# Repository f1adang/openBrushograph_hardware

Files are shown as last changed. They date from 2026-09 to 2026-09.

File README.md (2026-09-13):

# openBrushograph
openBrushograph
A simple, open source and DIY x-y gantry and z-mechanism for making a brush painting robot. Formerly know as Brušograf...

## Quick links
- `X-Y_freeCAD/`: Parametric FreeCAD gantry models and STLs
- `Z-mechanism_openSCAD/`: Parametric OpenSCAD brush lift models and STLs
- LICENSES/: CERN-OHL-S/W/P and CC BY-SA texts

## Overview
openBrushograph is a small CNC-style plotter for brushes and pens. The X–Y gantry is modeled in FreeCAD and the Z mechanism in OpenSCAD.

Full background, tutorials and history live on the SGMK wiki:
https://wiki.sgmk-ssam.ch/wiki/Brushograph

openBrushograph

## Downloads (FreeCAD & Pre-exported STLs)

If you just want to get printing immediately, you can grab the FreeCAD source file or the pre-exported STL folders below:
- **FreeCAD Source File:** [brushograf_V6.FCStd](X-Y_freeCAD/brushograf_V6.FCStd)

### Standard Version
- **Mini Variant (M3=2.7mm):** [STLs/brushograf_V6_Mini_M3_2.7mm_STLs](X-Y_freeCAD/STLs/brushograf_V6_Mini_M3_2.7mm_STLs/)
- **Z-Mechanism STLs:** [Z-mechanism_V4_STL](Z-mechanism_openSCAD/Z-mechanism_V4_STL/)

### Special Designs
- **Micro Variant (M3=2.7mm):** [STLs/brushograf_V6_Micro_M3_2.7mm_STLs](X-Y_freeCAD/STLs/brushograf_V6_Micro_M3_2.7mm_STLs/)

*Note: Endless custom versions can be generated using the FreeCAD parameters! For example, you can easily adjust the hole sizes to perfectly fit heated metal threaded inserts, or completely change the general dimensions of the gantry to suit your specific needs (see the **Parametric FreeCAD Design** section below).*

## Parametric FreeCAD Design
The X-Y gantry is designed in FreeCAD as a fully parametric model. 

### Adjusting Parameters
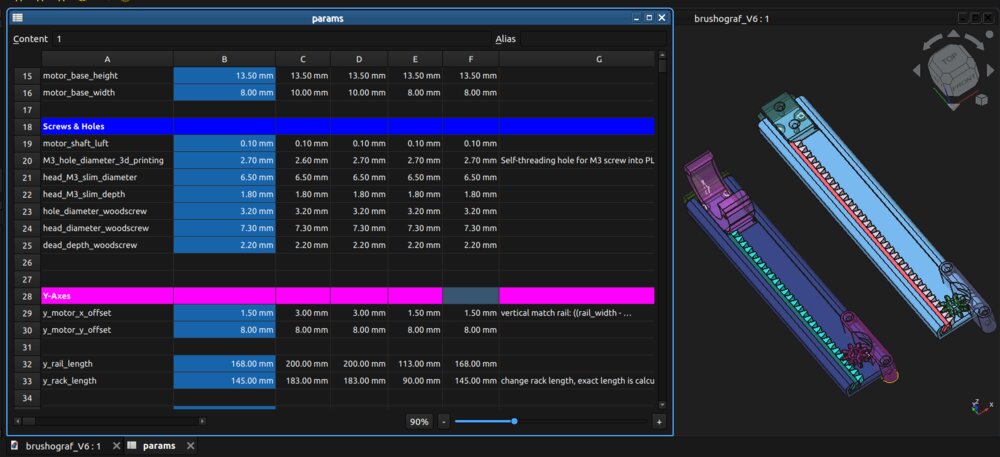
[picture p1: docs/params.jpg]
Spreadsheet Parameters


Inside the FreeCAD file (`X-Y_freeCAD/brushograf_V6.FCStd`), you will find a dedicated Spreadsheet object called `params`. This spreadsheet drives the entire 3D geometry!
- You can easily customize the design by modifying values in the parameter rows (e.g., changing the `M3_hole_diameter_3d_printing`).
- The design supports multiple **variants** (e.g., Mini, Micro, Baby). The variant names are defined as column headers in the first row of the spreadsheet (starting from column C).
- By changing the master Switcher value (cell `B1`) to the corresponding column index (1 for C, 2 for D, etc.), FreeCAD will instantly recompute the entire model for that specific variant!

### Automated STL Export Script
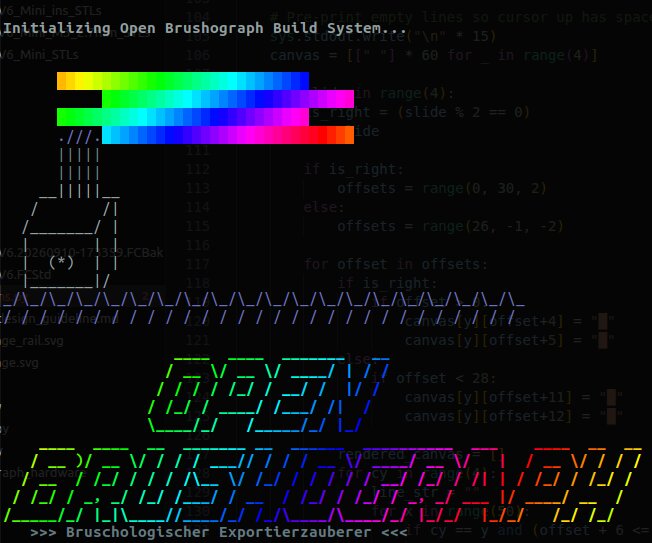
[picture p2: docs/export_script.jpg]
Terminal Export Wizard


To streamline the export process, we include a python build script (`build_versions.py`). 
Running this script via FreeCAD's command line will:
1. Dynamically read your custom variant names from the spreadsheet.
2. Provide an interactive terminal wizard to select which variants you want to build (or build all of them!).
3. Allow you to override specific parameters on the fly (like the M3 hole diameter).
4. Automatically toggle the spreadsheet switcher, force a deep geometry recompute, and export clean STL folders ready for 3D printing directly into the `X-Y_freeCAD/STLs/` directory.

**How to run the script:**
Open a terminal inside the `X-Y_freeCAD` directory and run:
```bash
FreeCADCmd build_versions.py brushograf_V6.FCStd
```
*(Note: Depending on your OS and installation, the FreeCAD command line tool may be named `freecadcmd`, `FreeCADCmd`, or accessed via flatpak: `flatpak run --command=FreeCADCmd org.freecad.FreeCAD`)*

## Parametric OpenSCAD Z-Mechanism
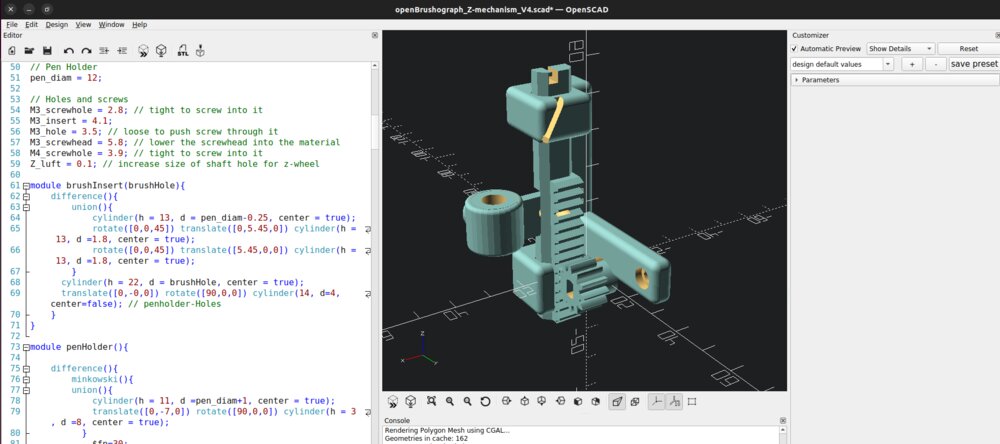
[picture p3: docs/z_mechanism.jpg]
OpenSCAD Z-Mechanism


In addition to the FreeCAD X-Y gantry, the Z-mechanism for the brush lift is also fully parametric, designed natively in OpenSCAD!
- You can find the source file and pre-compiled STLs in the `Z-mechanism_openSCAD/` directory.
- Simply open the `.scad` file in OpenSCAD and you can easily tweak variables like mounting hole sizes, brush holder dimensions, and motor fittings before generating your custom STL.

### Extra OpenSCAD Accessories
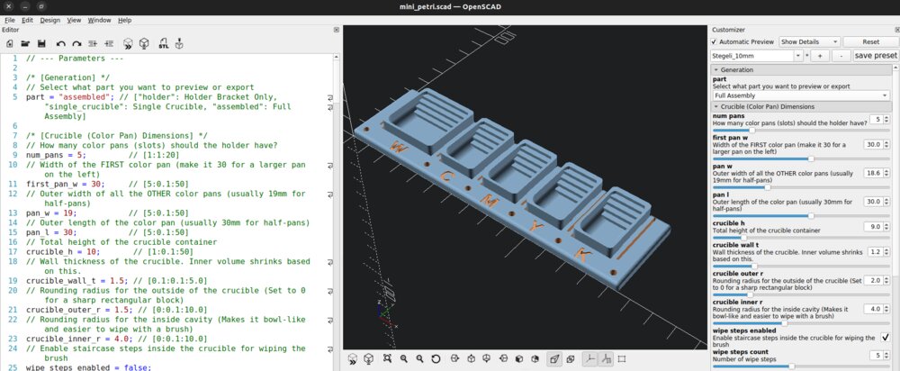
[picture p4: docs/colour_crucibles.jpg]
OpenSCAD Accessories


The OpenSCAD directory also includes parametric models for various extra parts! You can easily generate custom colour holders, petri dishes, and other useful accessories to complete your robotic painting setup.

## Setup options (controllers/firmware)
- FluidNC (ESP32 with WebUI): https://installer.fluidnc.com/
  - About FluidNC: http://wiki.fluidnc.com/en/home
- Arduino (GRBL): https://github.com/gnea/grbl
  - GRBL fork for 28BYJ-48 unipolar steppers: https://github.com/TGit-Tech/GRBL-28byj-48
- Universal Gcode Sender (UGS): https://winder.github.io/ugs_website/

See details and tips on the wiki: https://wiki.sgmk-ssam.ch/wiki/Brushograph#How_to_set_it_up

## Printing and Assembly
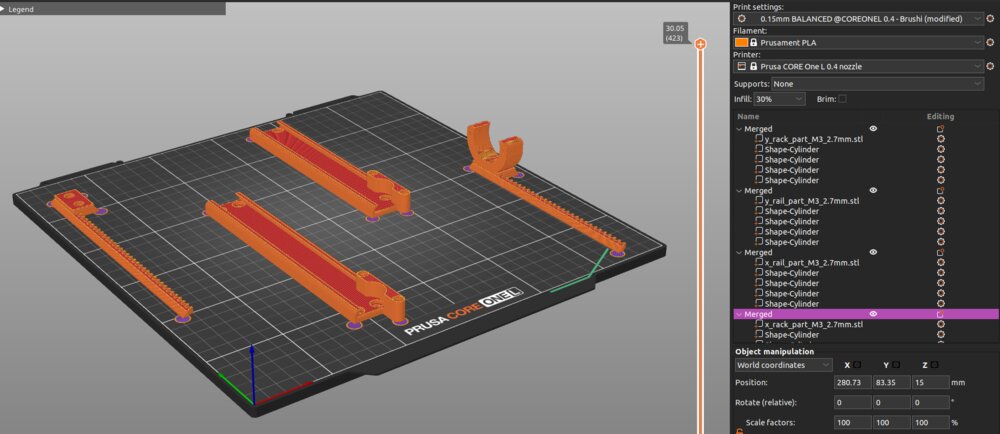
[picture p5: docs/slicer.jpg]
Prusa Slicer Preview


### Recommended Materials
For mechanical rigidity and durability, **PLA+** or better **High Temperature PLA+**, other materials such as **PETG** is highly recommended. Standard PLA is also acceptable but may be brittle under high stress or will bend easily in warm environments or in direct sunshine.

The pinions were also printed in other advanced filaments, such as PA612-CF15 for even better mechanical and thermal properties.

### Slicer Settings
For structural parts (like the gantry mounts and Z-mechanism):
- **Perimeters/Walls:** 3 to 4 walls for maximum structural strength.
- **Infill:** 20% to 30% Gyroid.
- **Layer Height:** 0.2mm is an excellent balance between speed and tolerance. For aesthetic reason smaller layer heights can be used.
- **Mouse-ears** are more usefull than larger brims if you have adhesion issues.

### Orientation and Supports
- The pre-exported STLs are generally oriented in their optimal printing position. 
- All parts are designed to print completely **support-free**.

### Hardware and Assembly
- **Threaded Inserts:** Hols can designed specifically for heated metal threaded inserts (e.g. M3). Use a soldering iron to press them in carefully.
- If you find the default hole sizes are too tight or loose for your specific inserts, remember you can always tweak the `M3_hole_diameter_3d_printing` parameter in the FreeCAD spreadsheet and re-export the STLs using the build script!

More context, detailed assembly instructions and legacy designs: https://wiki.sgmk-ssam.ch/wiki/Brushograph#Printing_and_assembling_the_Brushograph

## Bill of Materials (BOM) (in progress...)
A quick overview of the required printed parts and hardware is below:

### X-Y Assembly
| Assembly | Part | Qty | Notes |
|---|---|-----|---|
| X | `openBrushograph_x_rail_part.stl` | 1 | Print |
| X | `openBrushograph_x_rack_part.stl` | 1 | Print; higher infill recommended |
| X | `openBrushograph_x_pinion_part.stl` | 1 | Print (its same as y_pinion) |
| X | `openBrushograph_x_endstop_part.stl` | 1 | Print |
| Y | `openBrushograph_y_rail_part.stl` | 1 | Print |
| Y | `openBrushograph_y_rack_part.stl` | 1 | Print; higher infill recommended |
| Y | `openBrushograph_y_pinion_part.stl` | 1 | Print (its same as x_pinion) |

### Z Assembly
| Assembly | Part | Qty | Notes |
|---|---|-----|---|
| Z | `openBrushograph_rail_Z-mechanism.stl` | 1 | Print |
| Z | `openBrushograph_rack_Z-mechanism.stl` | 1 | Print |
| Z | `openBrushograph_handWheel.stl` | 1 | Print |
| Z | `openBrushograph_penHolder_Insert_6.5.stl` | 1 | Variants available for different brushes |

### Screws & Hardware
| Type | Image | Part | Qty | Notes |
|---|---|---|-----|---|
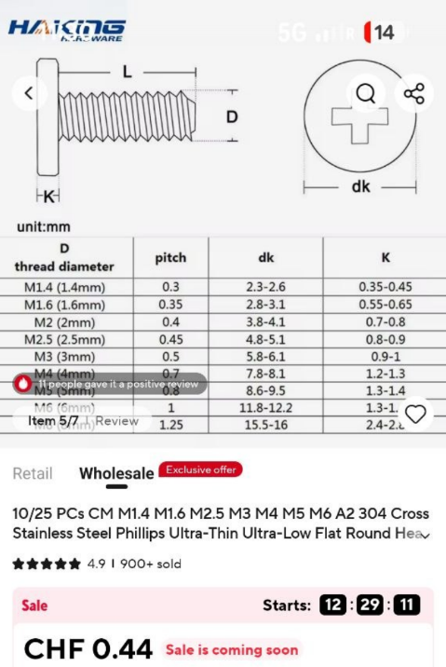
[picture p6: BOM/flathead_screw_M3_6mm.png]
| flat-head Screw | [](BOM/flathead_screw_M3_6mm.png) | M3x6 | 4 | to fit below the rack into the rails. [Shop Link](https://www.aliexpress.com/item/1005003126053325.html) |
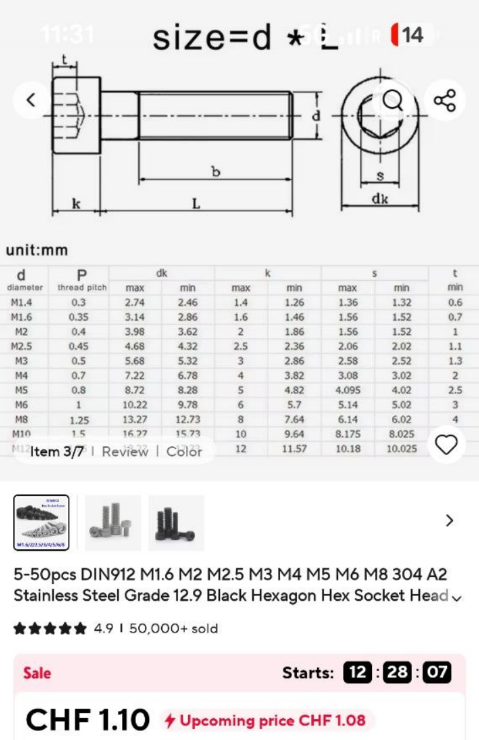
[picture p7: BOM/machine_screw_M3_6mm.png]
| machine Screw | [](BOM/machine_screw_M3_6mm.png) | M3x6 | 6 | to mount the motors. mbe use longer ones on the z-axes. [Shop Link](https://www.aliexpress.com/item/32810872544.html) |
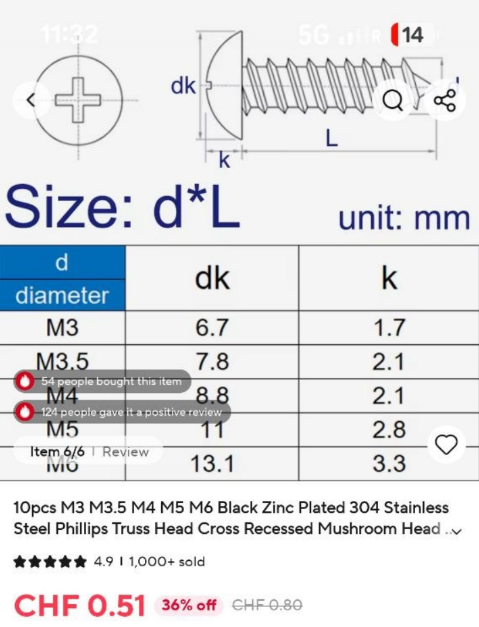
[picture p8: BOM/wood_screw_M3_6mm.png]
| Wood-Screw | [](BOM/wood_screw_M3_6mm.png) | M3x6 | 4 | Longer screws if you have a thick wooden base board. [Shop Link](https://www.aliexpress.com/item/1005009268426636.html) |
| Screw | | M4x16 | 1 | for handWheel |

### Optional: Threaded Inserts
| Type | Part | Qty | Notes |
|---|---|-----|---|
| Threaded Insert | M3 | 10 | For a stronger assembly. |

*Note: If you are using threaded inserts, a different model variant with wider holes has to be printed, or the standard holes can simply be drilled out with a 4mm drill bit to make them wider.*

### Electronics / PCB
The BOM and design files for the custom printed circuit board (PCB) are documented in a dedicated repository:
[Brushograph_PCB](https://github.com/openBrushograph/Brushograph_PCB)

Brushograph PCB

## Related links and credits
### Credits
General openBrushograph concept and artistic director, Dominik Mahnic: https://app.assembla.com/spaces/dominik-mahnic/wiki
X–Y: FreeCAD version designed by Stahl: https://github.com/stahlnow
Z: OpenSCAD version designed by dusjagr: https://github.com/dusjagr

### Where the inspirations came from
- Z-mechanism inspiration (Thingiverse): https://www.thingiverse.com/thing:7050508
- Earlier mini plotter references:
  - https://www.thingiverse.com/thing:4579436
  - https://www.thingiverse.com/thing:4607077
  - https://www.thingiverse.com/thing:4796222
  - https://www.thingiverse.com/thing:5719788
 
## License
- Hardware: CERN-OHL-S-2.0 (see LICENSE and LICENSES/)
- Documentation: CC BY-SA 4.0

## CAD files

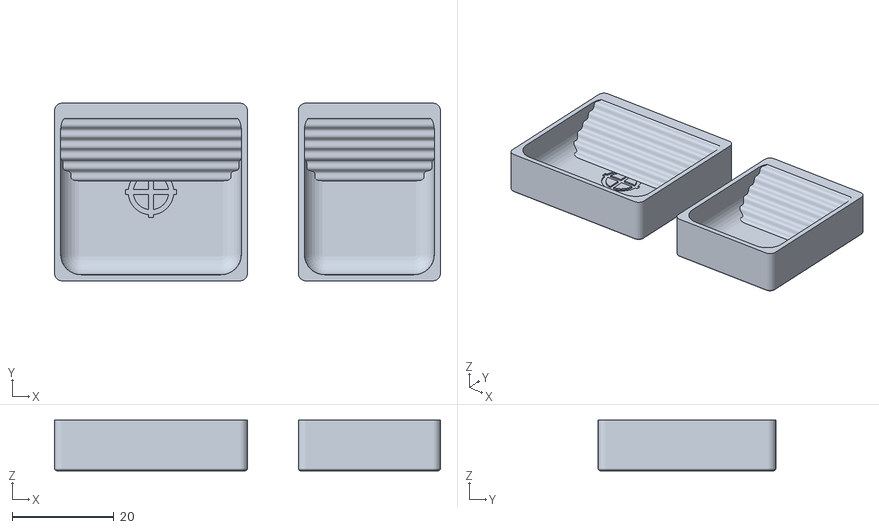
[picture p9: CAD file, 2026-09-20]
Extras/CMYK_ColourContainers/CMYK_standard_containers_steps.stl
76.0 x 35.0 x 10.0

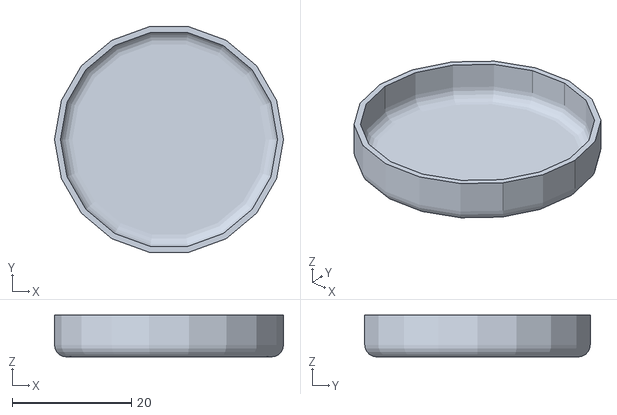
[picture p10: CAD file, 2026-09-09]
Extras/petri_ColourContainers/Petri39mm.obj
38.4 x 37.8 x 7.00

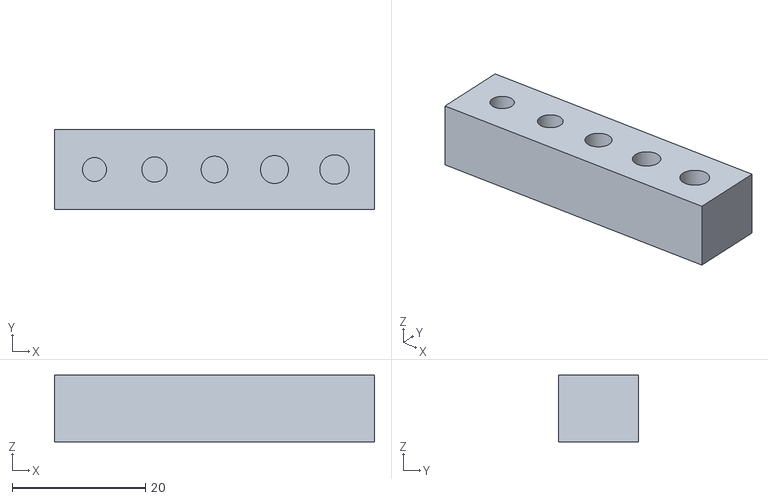
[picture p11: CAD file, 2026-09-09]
Extras/tests/insert_test.stl
48.0 x 12.0 x 10.0

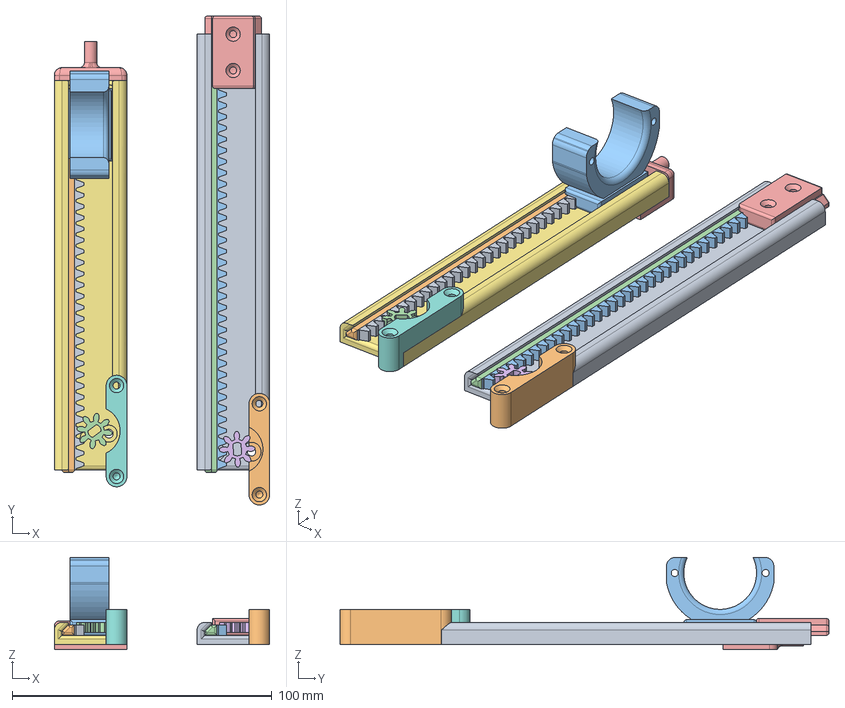
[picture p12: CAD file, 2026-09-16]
X-Y_freeCAD/brushograf_V6.FCStd
83.0 x 188.4 x 35.5 mm
y_rail
y_motor_base
y_rack
y_rack_fit
y_carriage
y_pinion
x_rail
x_motor_base
x_rack
x_rack_fit
x_carriage
x_pinion
x_endstop

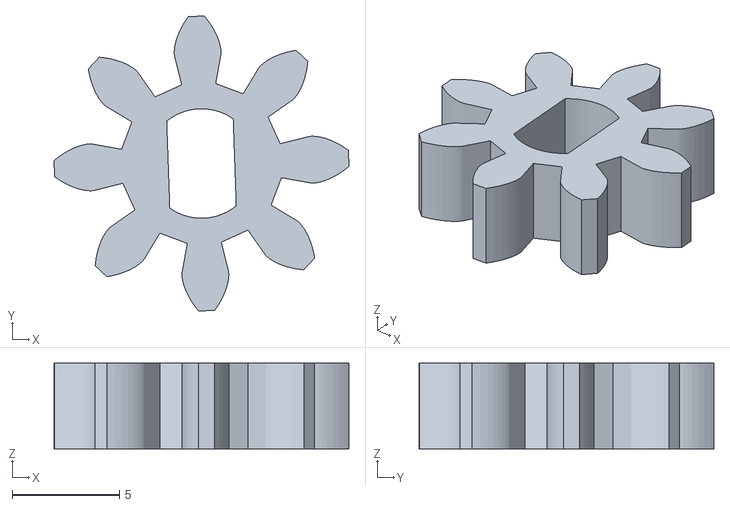
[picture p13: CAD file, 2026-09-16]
X-Y_freeCAD/STLs/brushograf_V6_Mikro_M3_2.7mm/y_pinion_Mikro_M3_2.7mm.stl
13.7 x 13.7 x 4.00

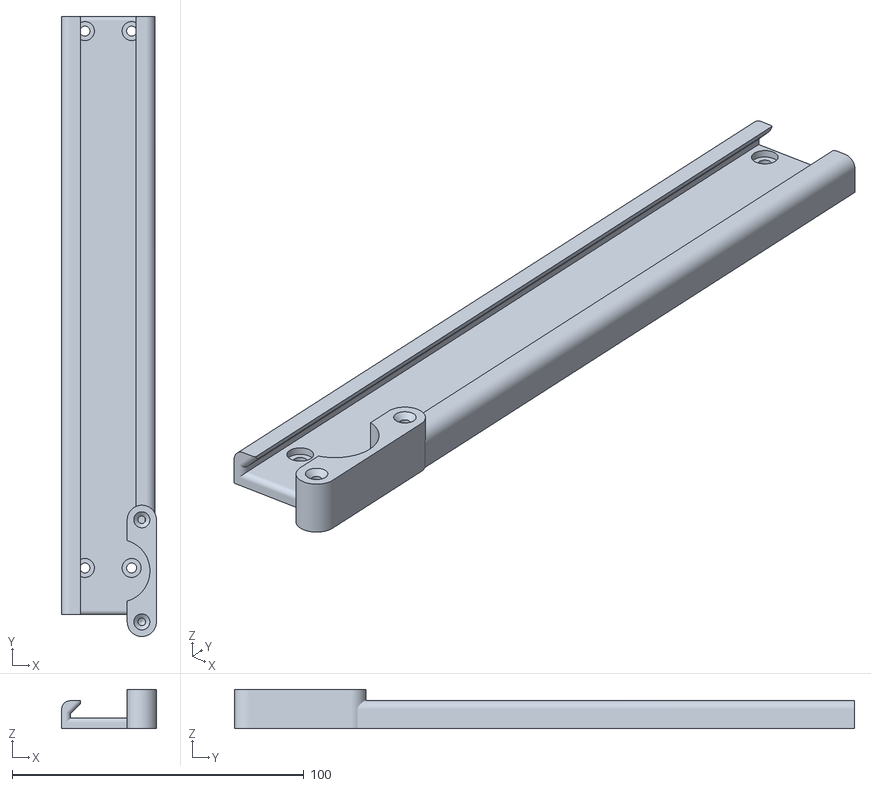
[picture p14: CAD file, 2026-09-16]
X-Y_freeCAD/STLs/brushograf_V6_Mini_M3_2.7mm/x_rail_Mini_M3_2.7mm.stl
32.5 x 212.5 x 13.5

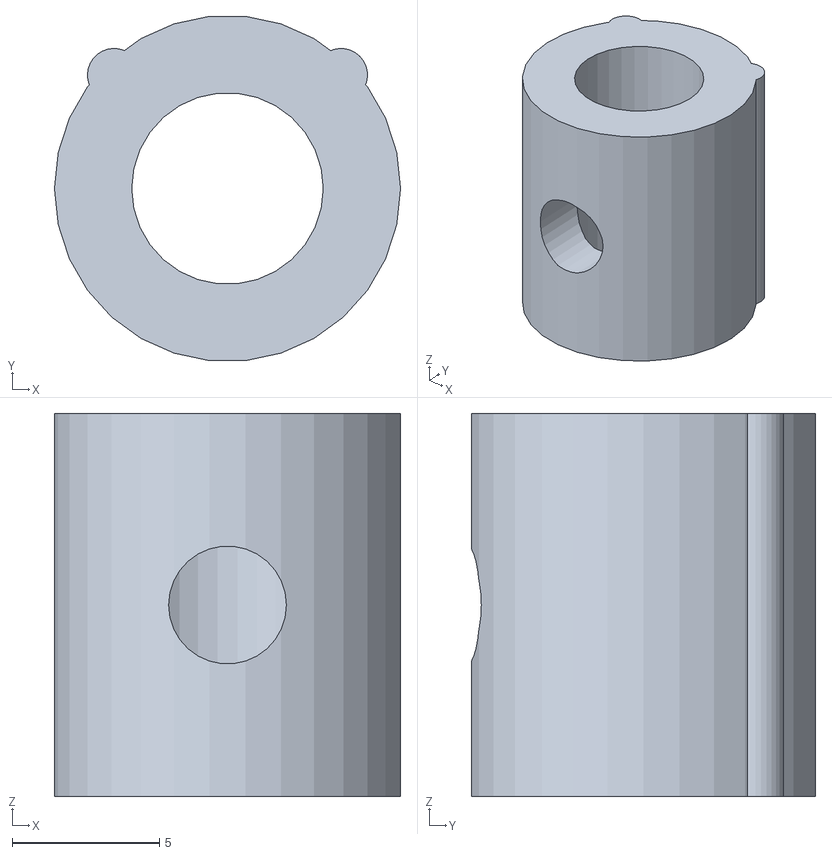
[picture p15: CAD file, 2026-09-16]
Z-mechanism_openSCAD/brushHolder/standard_brush_insert_6.5mm_Z-mechanism.stl
11.8 x 11.7 x 13.0

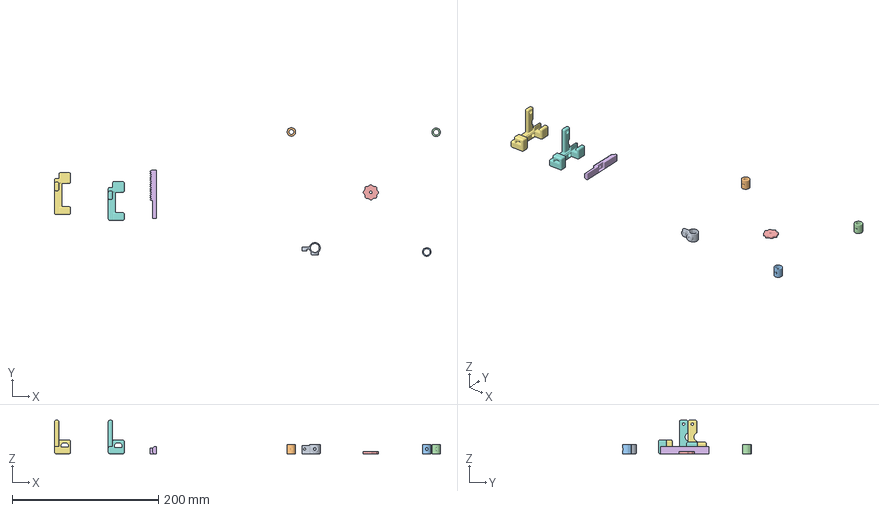
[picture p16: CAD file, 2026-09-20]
Z-mechanism_openSCAD/PrusaOne_Z-mechanism.3mf
528.1 x 176.0 x 46.0 mm
penHolder_Z-mechanism.stl
insert_65_Z-mechanism_V4.stl
insert_9_Z-mechanism_V4.stl
insert_75_Z-mechanism_V4.stl
handWheel_Z-mechanism.stl
standard_rackpen_Z-mechanism.stl
standard_rail_Z-mechanism.stl
mikro_high-rail_Z-mechanism.stl

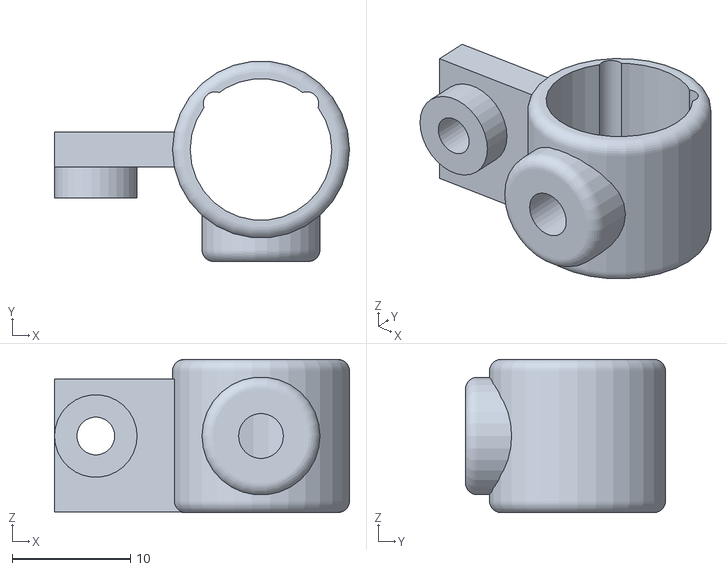
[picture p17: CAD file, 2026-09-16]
Z-mechanism_openSCAD/Z-mechanism_STL/mikro/brushHolder/mikro_pen_holder_12mm_Z-mechanism.stl
25.0 x 17.0 x 13.0

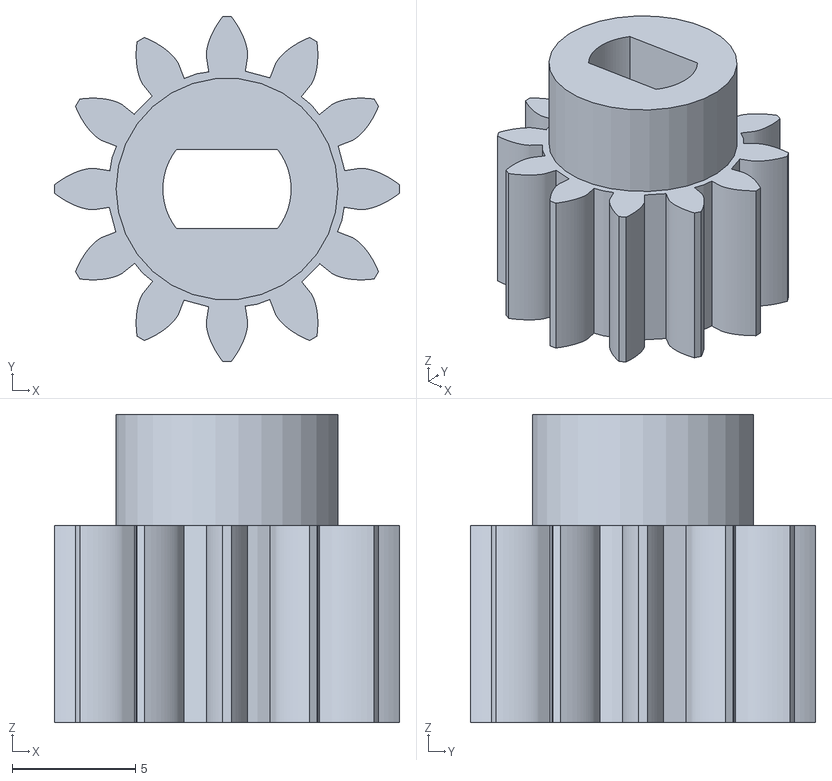
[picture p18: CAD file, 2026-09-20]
Z-mechanism_openSCAD/Z-mechanism_STL/mikro/mikro_gearwheel_Z-mechanism.stl
14.0 x 14.0 x 12.5

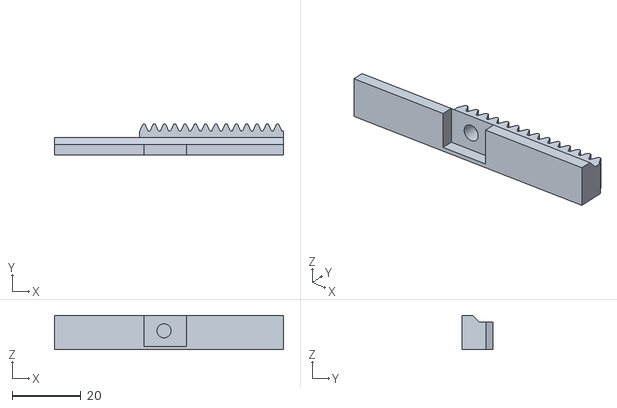
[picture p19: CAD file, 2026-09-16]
Z-mechanism_openSCAD/Z-mechanism_STL/standard/standard_rackpen_Z-mechanism.stl
66.5 x 8.95 x 10.0

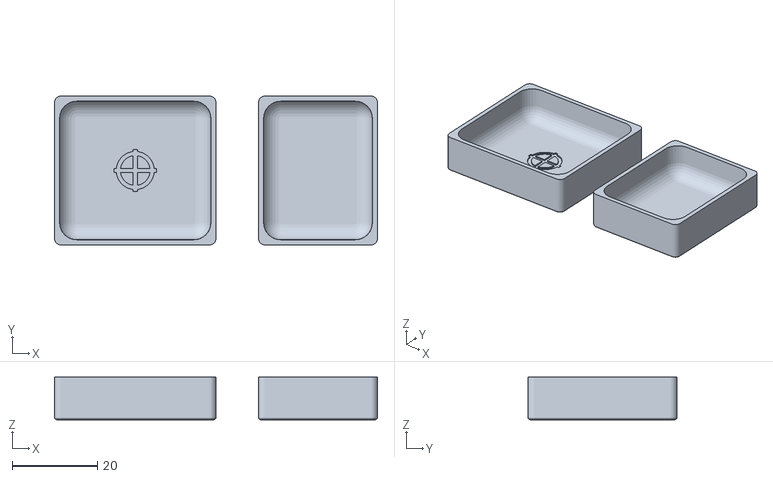
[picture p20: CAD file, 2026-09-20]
Extras/CMYK_ColourContainers/CMYK_standard_containers.stl
76.0 x 35.0 x 10.0

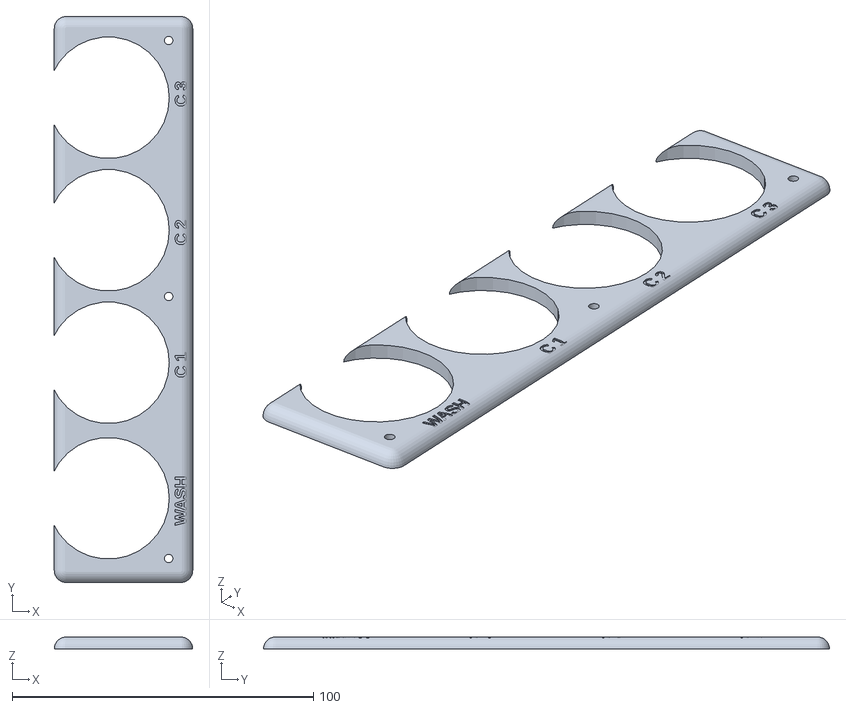
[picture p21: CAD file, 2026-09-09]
Extras/petri_ColourContainers/4xPetri_rounded_new.stl
46.0 x 188.0 x 3.98

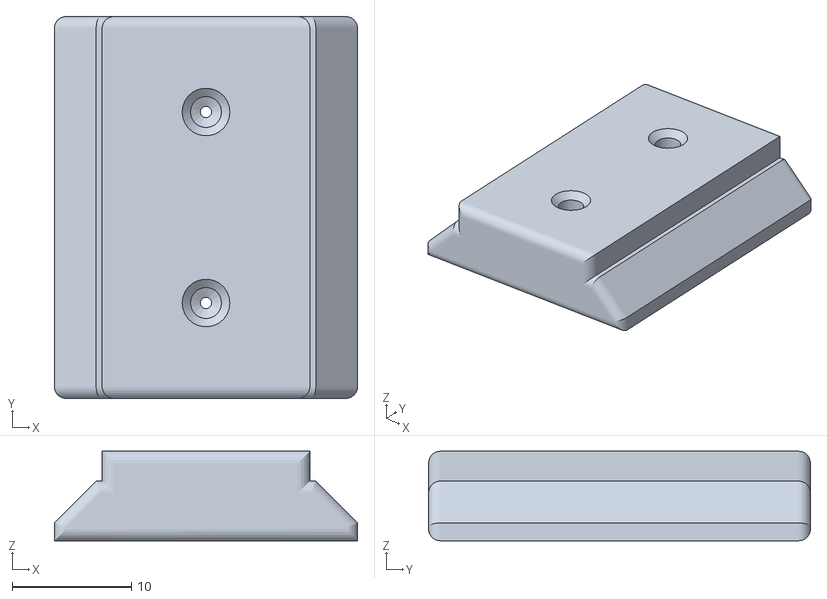
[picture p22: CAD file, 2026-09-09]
Extras/tests/test_carriage.stl
25.4 x 32.0 x 7.50

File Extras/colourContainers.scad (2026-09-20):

// --- Parameters ---

/* [Generation] */
// Select what part you want to preview or export
part = "assembled"; // ["holder": Holder Bracket Only, "single_crucible": Single Crucible, "assembled": Full Assembly]

/* [Crucible (Color Pan) Dimensions] */
// How many color pans (slots) should the holder have?
num_pans = 5;         // [1:1:20]
// Width of the FIRST color pan (make it 30 for a larger pan on the left)
first_pan_w = 30;     // [5:0.1:50]
// Outer width of all the OTHER color pans (usually 19mm for half-pans)
pan_w = 19;           // [5:0.1:50]
// Outer length of the color pan (usually 30mm for half-pans)
pan_l = 30;           // [5:0.1:50]
// Total height of the crucible container
crucible_h = 10;       // [1:0.1:50]
// Wall thickness of the crucible. Inner volume shrinks based on this.
crucible_wall_t = 1.5; // [0.1:0.1:5.0]
// Rounding radius for the outside vertical corners
crucible_outer_r = 1.5; // [0:0.1:10.0]
// Rounding radius for the outside bottom edges (Set lower for a flatter bottom)
crucible_outer_bottom_r = 0.5; // [0:0.1:10.0]
// Rounding radius for the inside cavity (Makes it bowl-like and easier to wipe with a brush)
crucible_inner_r = 4.0; // [0:0.1:10.0]
// Wipe style for the brush inside the crucible
wipe_style = "none"; // ["none": No Wipe, "steps": Staircase Steps, "ripples": Tilted Plane with Ripples]
// Number of wipe steps or ripples
wipe_count = 4; // [1:1:10]
// How much length of the crucible is taken up by the wiping area (0.4 = 40%)
wipe_length_pct = 0.4; // [0.1:0.05:0.8]
// For ripples: the height of the ripple bumps
wipe_ripple_h = 1.0; // [0.1:0.1:5.0]
// Amplitude of the wave snaking along X (Set to 0 for straight ripples)
wipe_snake_amp = 0.5; // [0:0.1:5.0]
// Wavelength of the snaking wave along X
wipe_snake_len = 15;  // [5:1:50]
// Height reached on the right side of the crucible (0.0 to 1.0, where 1.0 is full height)
wipe_right_height_pct = 0.25; // [0.0:0.05:1.0]
// Vertical offset to shift the entire ripple plane down (to prevent flat clipping at the top rim)
wipe_ripple_z_offset = 1.0; // [0:0.1:10.0]

/* [Target Mark (First Pan Only)] */
// Enable a target mark in the center of the first pan
target_mark = true;
// Depth of the target mark (negative = embossed cut into the floor, positive = extruded bump)
target_depth = -0.4; // [-2.0:0.1:2.0]

/* [Holder Dimensions] */
// Length of the dividing fingers behind the front flange (controls the holder depth)
finger_l = 30;        // [5:1:100]
// Rounding radius for the holder's top and side edges
holder_r = 2.0;       // [0:0.1:10.0]
// Extra gap to add around the crucible so it easily slides in and out of the holder
clearance = 0.1;      // [0:0.1:3.0]
// Gap distance between each pan slot
gap = 3.2;            // [0:0.1:20.0]
// Height (thickness) of the main holder plate
holder_h = 3;         // [1:0.1:20.0]
// Thickness of the walls around the slots
wall_t = 1.5;         // [0.5:0.1:10.0]
// Generate U-shape slots (open at the far end) or enclosed pockets
is_open_end = true;   
// Generate a solid bottom floor under the slots to prevent pans from falling through
has_bottom = false;   
// Thickness of the bottom floor (if enabled)
bottom_t = 1.5;       // [0.5:0.1:10.0]

/* [Spring Fingers] */
// Enable springy fingers between the crucibles (hollows the fingers and adds holding bulbs)
spring_fingers = true;
// Length of the flexible part of the finger
spring_finger_l = 28; // [5:1:50]
// Length of the gripping bulge (smaller value makes it more localized in the center)
spring_bulb_l = 10;   // [2:1:50]
// Width of the hollow slit cut into the fingers
spring_slit_w = 1.0;  // [0.2:0.1:5.0]
// Radius of the gripping bulbs protruding into the slots
spring_bulb_r = 0.5;  // [0.1:0.1:2.0]

/* [Labels] */
// Text labels to cut into the front flange for each slot
labels = ["W", "C", "M", "Y", "K"]; 
// Depth of the engraved text cut into the plastic
label_depth = 0.6;    // [0.2:0.1:2.0]
// Font size of the labels
label_size = 6;       // [2:1:20]

/* [Mounting & Flanges] */
// Length of the front solid flange area (perfect place to stick labels or text)
flange_l = 8;         // [5:1:50]
// Width of the solid area on the far left and right ends (used for mounting holes)
side_flange = 6;      // [0:1:50]
// Diameter of the screw mounting holes
mount_hole_d = 3;     // [1:0.1:10.0]
// Y-axis distance from the very front edge to the center of the mounting holes
mount_hole_y_offset = 4; // [1:0.1:20.0]

/* [Hidden] */

// --- Calculated variables ---
// The holder's outer dimensions and the center-to-center pitch of the pans
// are fixed and independent of clearance. Clearance only enlarges the subtracted slots.

function get_pan_w(i) = (i == 0) ? first_pan_w : pan_w;
function get_pan_x(i) = side_flange + (i == 0 ? 0 : first_pan_w + gap + (i - 1) * (pan_w + gap));

// Calculate total width using the first pan + all remaining pans
tot_w = (2 * side_flange) + first_pan_w + (num_pans > 1 ? (num_pans - 1) * (pan_w + gap) : 0);
front_wall = wall_t;
back_wall = is_open_end ? 0 : wall_t;
tot_l = flange_l + front_wall + finger_l + back_wall;
tot_h = has_bottom ? holder_h + bottom_t : holder_h;

module target_mark_shape(d) {
    // Crosshairs (2 perpendicular lines)
    translate([-5, -0.5, 0]) cube([10, 1.0, d]);
    translate([-0.5, -5, 0]) cube([1.0, 10, d]);
    
    // Outer circle
    difference() {
        cylinder(h = d, r = 4.5, $fn=32);
        translate([0, 0, -0.1]) cylinder(h = d + 0.2, r = 3.5, $fn=32);
    }
}

module top_rounded_box(w, l, h, r) {
    if (r <= 0.001) {
        cube([w, l, h]);
    } else {
        safe_r = min(r, min(w/2 - 0.001, l/2 - 0.001));
        
        intersection() {
            hull() {
                // Top corners (spheres)
                translate([safe_r, safe_r, h - safe_r]) sphere(r=safe_r);
                translate([w-safe_r, safe_r, h - safe_r]) sphere(r=safe_r);
                translate([safe_r, l-safe_r, h - safe_r]) sphere(r=safe_r);
                translate([w-safe_r, l-safe_r, h - safe_r]) sphere(r=safe_r);
                
                // Bottom corners (thick cylinders to prevent CGAL issues)
                translate([safe_r, safe_r, 0]) cylinder(r=safe_r, h=safe_r);
                translate([w-safe_r, safe_r, 0]) cylinder(r=safe_r, h=safe_r);
                translate([safe_r, l-safe_r, 0]) cylinder(r=safe_r, h=safe_r);
                translate([w-safe_r, l-safe_r, 0]) cylinder(r=safe_r, h=safe_r);
            }
            cube([w, l, h]);
        }
    }
}
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

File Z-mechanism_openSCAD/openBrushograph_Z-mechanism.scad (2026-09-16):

$fn = 30;

// Redesigned and modified from https://www.thingiverse.com/thing:5719788
// Now available in OpenSCAD, for further modifications
// Gears from: https://www.thingiverse.com/thing:1604369
// Its mostly in german, but you should be ok...
// To Do:
// Implement gears as imported library

/* [Render Selection] */
// Which part to display?
part_to_render = "assembly"; // [assembly:Full Assembly, core:Core Assembly (Rail/Rack/Gear), rail:Z Rail, gearwheel:Z Gearwheel, rackpen:Z Rackpen, pen_holder:Pen Holder, brush_insert:Brush Insert, hand_wheel:Hand Wheel]
// Resolution of rounded edges in Preview mode (F5)
preview_fn = 12; // [4:2:32]
// Move the rack up and down in the assembly view to check collisions
assembly_z_travel = -9; // [-30:0.5:20]

/* [General Shape] */
// Diameter of the spherical tool used to round corners (don't exceed 5)
round_edge = 4;
// Extra clearance added to the rail's guide channel to let the rack slide freely
slide_tol = 0.3;
// Adjusts the gear mesh depth by moving the rack closer to the gearwheel (increase if gearwheel is smaller)
tight = 2.4;
// Baseline X-axis offset for the rack's internal geometry
dist = 2.8;
// The total usable Z travel distance (up + down)
z_travel_range = 18; // [10:0.5:50]
// Include cutouts for Rubber Holder on the Z Rail
include_rubber_holder = false;

/* [Gears and Wheels] */
// How much of the available travel space to fill with teeth
teeth_ratio = 1; // [0.1:0.05:1.0]
// Helical angle for the gear and rack teeth (0 = straight teeth)
tooth_angle = 0;
// Module of the gear (height of the tooth tip above the pitch line)
tooth_size = 1;
// Overall width of the rack
rackWidth = 8;
// Overall depth/thickness of the rack (do not change from 6 due to hardcoded dependencies)
rackDepth = 6;

/* [Pen Holder] */
// Diameter of the pen/brush to be inserted
pen_diam = 12;
// Diameter of the hole in the brush insert
brush_hole_diam = 6.5;
// Offset the pen holder up or down along the rack
pen_z_offset = 6; // [-20:1:20]

/* [Holes and Screws] */
// Diameter for holes where M3 screws self-tap directly into the plastic
M3_screwhole = 2.8;
// Diameter for holes designed to receive heated M3 brass threaded inserts
M3_insert = 4.1;
// Diameter for loose clearance holes where M3 screws pass through freely
M3_hole = 3.5;
// Diameter of the counterbore to hide M3 screw heads inside the material
M3_screwhead = 5.8;
// Diameter for holes where M4 screws self-tap directly into the plastic
M4_screwhole = 3.9;
// Additional tolerance (air) added to the stepper motor D-shaft hole to ensure it fits easily
Z_luft = 0.1;

/* [Hidden] */
// Command line override for part_to_render
export_part = "";
// Command line override for pen_diam
export_pen_diam = 0;
// Command line override for brush_hole_diam
export_brush_hole = 0;

// Depth of the hole for the threaded insert in the rack
insert_depth = 10;
// Starting Y position of the insert hole (controls how far out the front it starts)
insert_start_y = 1;

// Uncomment if you have the StepMotor STL
// color("DarkSlateGray") translate([-25,8,9.6]) rotate([90,0,90]) import("StepMotorModelScaled.stl");

actual_part = (export_part != "") ? export_part : part_to_render;
actual_pen_diam = (export_pen_diam > 0) ? export_pen_diam : pen_diam;
actual_brush_hole = (export_brush_hole > 0) ? export_brush_hole : brush_hole_diam;

if (actual_part == "assembly") {
  ext_z = z_travel_range - 16.5 - pen_z_offset;
  Z_rail();
  Z_gearwheel();
  translate([0, 0, ext_z + assembly_z_travel]) Z_rackpen(M3_insert);
  translate([25.5, -6.8 + tight, 18.5 + ext_z + pen_z_offset + assembly_z_travel]) penHolder();
  translate([25.5, -6.8 + tight, 18.5 + ext_z + pen_z_offset + assembly_z_travel]) brushInsert(actual_brush_hole);
  translate([25.5, -10.8 + tight - 9.5, 18.5 + ext_z + pen_z_offset + assembly_z_travel]) rotate([90, 0, 0]) handWheel();
} else if (actual_part == "core") {
  ext_z = z_travel_range - 16.5 - pen_z_offset;
  Z_rail();
  Z_gearwheel();
  translate([0, 0, ext_z + assembly_z_travel]) Z_rackpen(M3_insert);
} else if (actual_part == "rail") {
  rotate([90, 0, 0]) Z_rail();
} else if (actual_part == "gearwheel") {
  rotate([0, 90, 0]) Z_gearwheel();
} else if (actual_part == "rackpen") {
  rotate([0, -90, 0]) Z_rackpen(M3_insert); // Alternatively use M3_screwhole
} else if (actual_part == "pen_holder") {
  penHolder();
} else if (actual_part == "brush_insert") {
  brushInsert(actual_brush_hole);
} else if (actual_part == "hand_wheel") {
  handWheel();
}

// Z-rack with mountable penHolder
module Z_rackpen(lochli) {
  translate([0, 0, 10]) difference() {
      color("fuchsia") translate([0, tight - 0.2, 15]) Z_rack();
      // Hole for threaded insert (red transparent for debugging depth)
      #translate([dist + 5.5, insert_start_y, 9.2 + pen_z_offset]) rotate([90, 0, 0]) cylinder(insert_depth, d=lochli, center=false);
      translate([dist + 6, -6.68 + tight, 8.8 + pen_z_offset]) cube([10, 3.1, 12.4], center=true);
      translate([dist + 6, -6.68 + tight, 50 + pen_z_offset]) cube([1.8, 18.1, 12], center=true);
      translate([dist + 6.8, -6.68 + tight, 45 + pen_z_offset]) cube([2.0, 18.1, 2], center=true);
    }
}

module brushInsert(brushHole) {
  difference() {
    union() {
      cylinder(h=13, d=actual_pen_diam - 0.25, center=true);
      rotate([0, 0, 45]) translate([0, 5.45, 0]) cylinder(h=13, d=1.8, center=true);
      rotate([0, 0, 45]) translate([5.45, 0, 0]) cylinder(h=13, d=1.8, center=true);
    }
    cylinder(h=22, d=brushHole, center=true);
    translate([0, -0, 0]) rotate([90, 0, 0]) cylinder(14, d=4, center=false); // penholder-Holes
  }
}

module penHolder() {

  difference() {
    minkowski() {
      union() {
        cylinder(h=11, d=actual_pen_diam + 1, center=true);
        translate([0, -7, 0]) rotate([90, 0, 0]) cylinder(h=3, d=8, center=true);
      }
      $fn = $preview ? preview_fn : 30;
      sphere(d=2);
    }
    cylinder(h=23, d=actual_pen_diam, center=true);
    rotate([0, 0, 45]) translate([0, 5.5, 0]) cylinder(h=23, d=2, center=true);
    rotate([0, 0, 45]) translate([5.5, 0, 0]) cylinder(h=23, d=2, center=true);

    translate([0, -2, 0]) rotate([90, 0, 0]) cylinder(20, d=3.8, center=false); // penholder-Holes
  }

  difference() {
    union() {
      translate([-11.5, 0, -0.8]) cube([12, 3, 11.3], center=true);
      translate([-14, -2.8, 0]) rotate([90, 0, 0]) cylinder(h=2.6, d=7, center=true);
    }
    #translate([-14, 10, 0]) rotate([90, 0, 0]) cylinder(20, d=3.2, center=false);
    cylinder(h=23, d=actual_pen_diam, center=true);
    // penholder-Holes
  }
}

module handWheel() {
  difference() {
    minkowski() {
      union() {
        cylinder(h=1.5, d=17, center=true);
      }
      $fn = $preview ? preview_fn : 30;
      sphere(d=1.5);
    }
    translate([0, -0, -2]) cylinder(14, d=3.7, center=false); // penholder-Holes
  }
  for (a = [0:45:360]) {
    rotate([0, 0, a]) translate([0, -8, 0]) cylinder(h=3, d=5, center=true);
  }
}
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

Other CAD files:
Z-mechanism_openSCAD/Z-mechanism_STL/standard/brushHolder/standard_pen_holder_12mm_Z-mechanism.stl
X-Y_freeCAD/STLs/brushograf_V6_Mikro_M3_2.7mm/x_rack_Mikro_M3_2.7mm.stl
X-Y_freeCAD/STLs/brushograf_V6_Mini_M3_2.7mm/y_rack_Mini_M3_2.7mm.stl
Z-mechanism_openSCAD/Z-mechanism_STL/mikro/brushHolder/mikro_brush_insert_6.5mm_Z-mechanism.stl
Extras/petri_ColourContainers/petriDishes_openBrushograph.scad
Z-mechanism_openSCAD/openBrushograph_Z-mechanism_V4.scad
Extras/CMYK_ColourContainers/CMYK_standard_containers_waveyripples.stl
Extras/CMYK_ColourContainers/CMYK_standard_holder.stl
Extras/CMYK_ColourContainers/mikro_CMYK_holder.stl
Extras/CMYK_ColourContainers/mikro_containers_noSteps.stl
Extras/CMYK_ColourContainers/mikro_containers_steps.stl
Extras/petri_ColourContainers/Extras_cover.stl
Extras/petri_ColourContainers/petriCross.obj
Extras/petri_ColourContainers/petriDish_high.stl
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

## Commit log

2026-09-09 sorted files
    [4xPetri_rounded.stl, 4xPetri_rounded_new.stl, Extras_cover.stl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]
2026-09-09 remove v3
    [V3_params.csv, openBrushograph_V3.FCStd, openBrushograph_Z-mechanism.scad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]
2026-09-10 Version 6 release and improved docu
    [brushograf_V4_insert.FCStd, brushograf_V6.FCStd, brushograf_mini-x_endstop.stl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]
2026-09-10 working on the bom
2026-09-13 improvind docs
    [BOM.csv, CMYK_crucibles_big.stl, CMYK_holder_big.stl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]
2026-09-15 chore: remove explicit version numbers from file and folder names
    [insert_5_Z-mechanism_V4.stl, insert_65_Z-mechanism_V4.stl, insert_75_Z-mechanism_V4.stl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]
2026-09-15 feat: add Customizer support with parameter tabs and render selection
    [openBrushograph_Z-mechanism.scad]
2026-09-15 feat: optimize preview rendering and align handWheel in assembly
    [openBrushograph_Z-mechanism.scad]
2026-09-16 kinda done with parametrized version
    [openBrushograph_Z-mechanism.scad, penHolder_Z-mechanism.stl, rack_Z-mechanism.stl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]
2026-09-16 cleaning up stl exports
    [handWheel_Z-mechanism.stl, openBrushograph_handWheel_Z-mechanism_V4.stl, openBrushograph_rack_insert41_Z-mechanism.stl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]
2026-09-16 fixed slide_tol bug
    [handWheel_Z-mechanism.stl, insert_5_Z-mechanism_V4.stl, insert_65_Z-mechanism_V4.stl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]
2026-09-16 generated all stl soon ready for a release
    [PrusaOne_Z-mechanism.3mf, mikro_brush_insert_6.5mm_Z-mechanism.stl, mikro_pen_holder_12mm_Z-mechanism.stl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]
2026-09-16 making new extra / colour containers
    [CMYK_crucibles_big.stl, CMYK_holder_big.stl, mikro_5x_petri.stl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]
2026-09-16 renamed files more consostently
    [brushograf_V6.FCStd, mikro_containers_noSteps.stl, x_endstop_Mikro_M3_2.7mm.stl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]
2026-09-17 still renaming files and sorting
    [4xPetri_rounded_new.stl, Extras_cover.stl, Petri39mm.obj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]
2026-09-19 added new containers
    [CMYK_standard_containers_rippled.stl, CMYK_standard_containers_tiltrippled.stl, CMYK_standard_holder.stl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]
2026-09-19 deletet legacy file
    [standard_CMYK_holder.stl]
2026-09-20 renamed containers
    [CMYK_standard_containers_straightripple.stl, CMYK_standard_containers_waveyripples.stl]
2026-09-20 resized containers to make it all a bit narrower. the NEW STANDARD
    [CMYK_standard_containers.stl, CMYK_standard_containers_steps.stl, CMYK_standard_containers_straightripple.stl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]
2026-09-20 edits parameters
    [PrusaOne_Z-mechanism.3mf]
2026-10-09 build_versions: refuse to export when the Gears add-on is missing
    The racks and pinions are Part::FeaturePython objects from the Gears
    add-on (freecad.gears). When that add-on can't be imported, FreeCAD
    restores them without a Proxy: they report Up-to-date, never recompute,
    and keep the shape saved in the .FCStd. Every variant then gets the
    saved variant's teeth - e.g. a Mini build exported Mikro racks
    (146.9 mm instead of 183.9 mm) on Mini-length rails, and Mikro pinions.
    silence_freecad() hid the restore error, so nothing looked wrong.
    Check for Python features with no Proxy right after opening the
    document, list them, point at the Gears workbench and exit before
    anything is exported.
    Co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
2026-10-11 Reinforce round X rack motor mount with gradual curved ears
    - Add gradual circular arcs (R = 5.09 mm) around the 28BYJ-48 stepper motor mounting holes (X = ±17.5 mm, Y = 18.0 mm).
    - Increase wall thickness adjacent to mounting holes from 1.80 mm to 3.74 mm (+108% material reinforcement) to prevent brittleness and layer splitting under screw torque.
    - Maintain inner diameter strictly at Ø 28.00 mm for motor fit.
    - Preserve top collar flat width at 6.00 mm and bottom arcs untouched without global thickening.
    - Cleanly constrain Sketch029 (0 DOF, fully constrained, 0 redundant).
    - Recompute and update exported x_rack STLs.
    - Add visual comparison documentation in docs/x_rack_motor_mount_reinf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
2026-10-12 Reinforce Z-mechanism rail stepper motor mount with angled gussets
    - Eliminate 90° right-angle cantilever breakpoint where the horizontal motor mount bar (`Balken`) joins the vertical spine (`Vertikal`) by adding a 45° top angled gusset spanning to Z = 32 mm.
    - Add bottom angled reinforcement extending directly to the edge of the Ø 12 mm motor gearpin / center hole cutout (Y ≈ 2.34 mm at Z = 2 mm).
    - Connect the bottom reinforcement seamlessly into the adjacent bottom guide block across X ∈ [-6.0, 2.5] mm, eliminating the undercut gap and forming a continuous solid structure flush with the guide block front wall.
    - Maintain flat stepper motor mounting face at X = -6.0 mm.
    - Ensure 0 i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
2026-10-12 build_versions: skip variants whose recompute fails
    When a feature fails to recompute - e.g. a fillet whose edge reference
    no longer resolves at another variant's size - FreeCAD marks it Invalid,
    leaves its body Touched with the previous variant's shape, and
    Mesh.export writes that stale shape anyway. With the reinforced X rack
    motor mount (PR #2), Fillet011 loses its edges on the 32 mm variants
    and the Mini x_rack came out with the Mikro carriage in mid-rail.
    After the recompute, list any Invalid object with its status message
    and export nothing for that variant; report failed variants at the end.
    Also flush stdout before the final os._exit so the summary isn't lost
    when output is piped.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
2026-10-12 X rack motor mount: pin ears to the screw holes, round corners in the sketch
    Fillet011 rounded six corners of the motor holder by edge reference. On
    the 32 mm variants (Mini, Yours?) FreeCAD lost the names of the three
    edges at the ear joints, the fillet went Invalid and x_carriage kept the
    previous variant's shape - the Mini x_rack came out with the Mikro
    carriage in mid-rail. Recreating the fillet did not help.
    - Draw the six R3 rounds in Sketch029 and delete Fillet011, so nothing
    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
2026-10-12 Z rail: keep the bottom gusset 1 mm clear of the gearwheel face
    The bottom motor-mount gusset was drawn up to X = 2.5, the gearwheel's
    side face, and reaches inside the gear's tip circle to meet the shaft
    hole. Only the minkowski rounding kept it off the teeth: the gap was
    0.10-0.12 mm (nothing on main comes within 1 mm), which a printed part
    and a gear pushed onto the shaft would close.
    Derive the gusset's X extent instead: from the motor face to
    gear_face_clearance (new parameter, 1 mm) short of the gear face, using
    gear_x, which Z_gearwheel now also uses for its position.
    Checked for both presets: gear clearance 1.10-1.15 mm; hub, rack over
    its travel, motor screw access and motor face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
2026-10-12 Z mechanism: re-export the mikro rackpen
    The committed mikro rackpen predates the current .scad and mikro preset:
    3 mm shorter and 6 % less volume than a fresh export (3222.6 vs
    3437.5 mm3). This PR re-exports the mikro rail, so without this the
    mikro set would pair the current rail with the old, shorter rack.
    Exported as export_stls.sh does it; matches a fresh render in volume
    and bounding box.

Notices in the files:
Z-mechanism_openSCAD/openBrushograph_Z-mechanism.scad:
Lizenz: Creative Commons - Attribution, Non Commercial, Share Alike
